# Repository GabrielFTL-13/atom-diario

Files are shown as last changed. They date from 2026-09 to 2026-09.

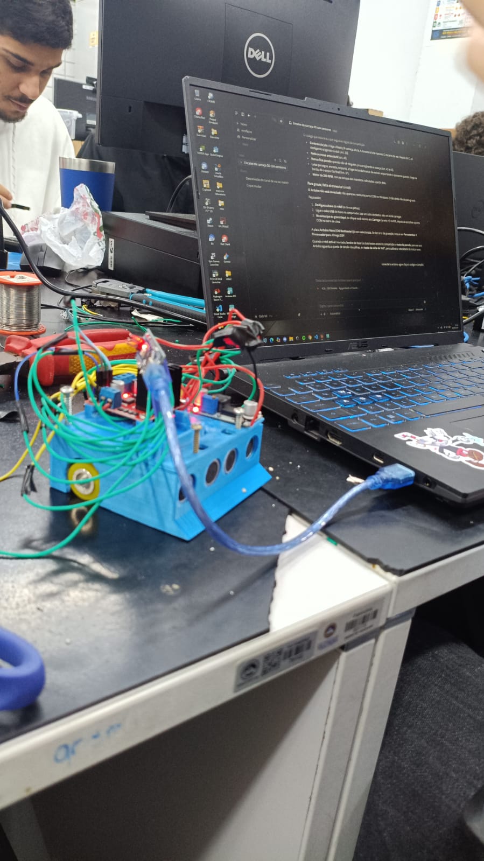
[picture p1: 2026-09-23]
img/fotos/laboratorio.jpg

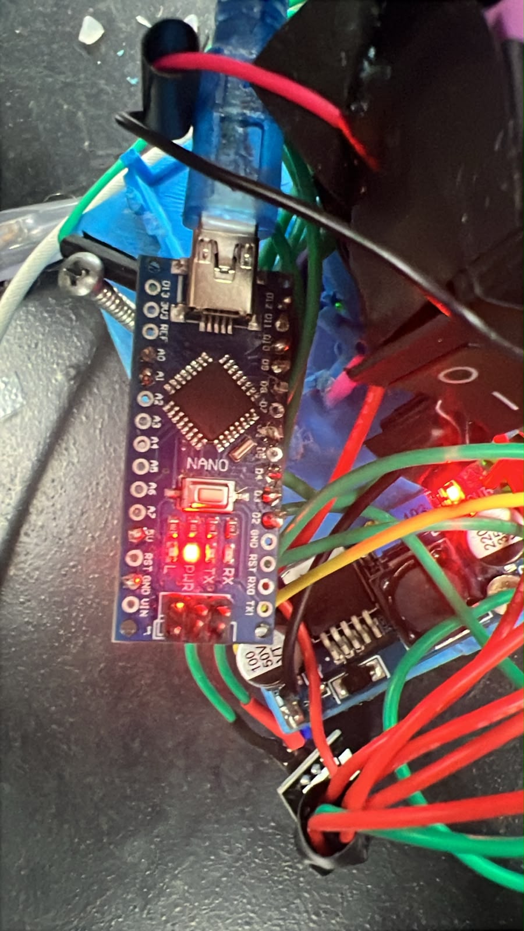
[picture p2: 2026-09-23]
img/fotos/nano_usb.jpg

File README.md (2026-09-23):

# Atom — mini sumô da UVV

Diário de bordo do **Atom**, o robô de mini sumô que a equipe levou ao **Sumô Tech Fight**
do **InovaWeek 2026** (UVV, Vila Velha, ES). O apelido dele é Frankenstein.

**Equipe:** Gabriel Fernandes, Gustavo Fernandes, Rafaela Ribeiro, Edvaldo Neto e Ana Lívia
— 2º período de Engenharia de Software, orientação do professor Abrantes.

## O site

`index.html` é o caderno completo: modelo 3D que gira, fotos, a história dos problemas e o
código gravado no robô. Abra o arquivo no navegador ou publique com o GitHub Pages
(Settings → Pages → Deploy from a branch → `main` / `root`).

## O que tem aqui

| Pasta | O que é |
| --- | --- |
| `index.html`, `modelo_r5.js`, `img/` | o site |
| `codigo/mini_sumo_uvv/` | o firmware do robô (backup 2), para Arduino Nano |
| `modelo-3d/stl/` | os STLs que foram impressos |
| `modelo-3d/openscad/` | o modelo em OpenSCAD |
| `modelo-3d/vistas/` | as vistas geradas do modelo |

## O robô

- 95 × 95 mm, 45,3 mm de altura montado
- Arduino Nano (ATmega328P), ponte H L298N
- 2× HC-SR04, 2× TCRT5000, receptor infravermelho de 38 kHz
- motores N20 de 200 RPM, rodas de 22 mm
- 2× 18650 em série com LM2596 regulando 5 V

O firmware precisa da biblioteca **IRremote 4.x** (shirriff, z3t0, ArminJo) e da placa
Arduino Nano com processador ATmega328P.

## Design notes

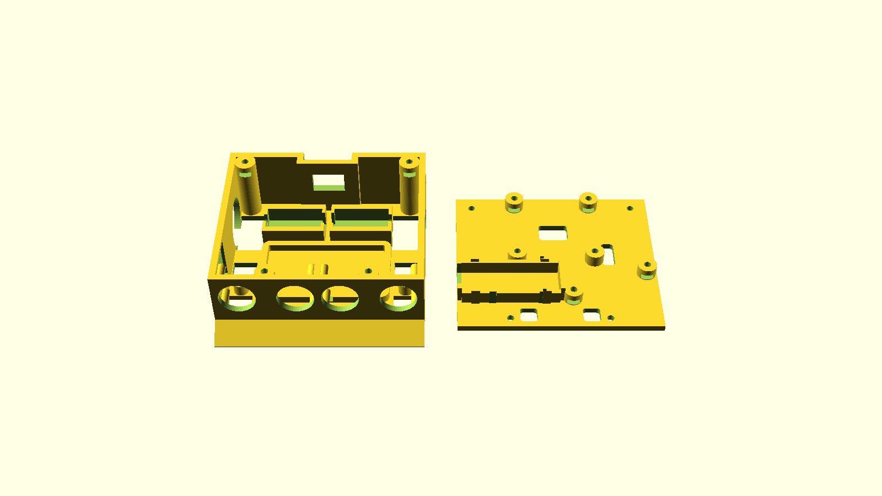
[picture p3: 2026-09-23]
img/vista_impressao_r5.png

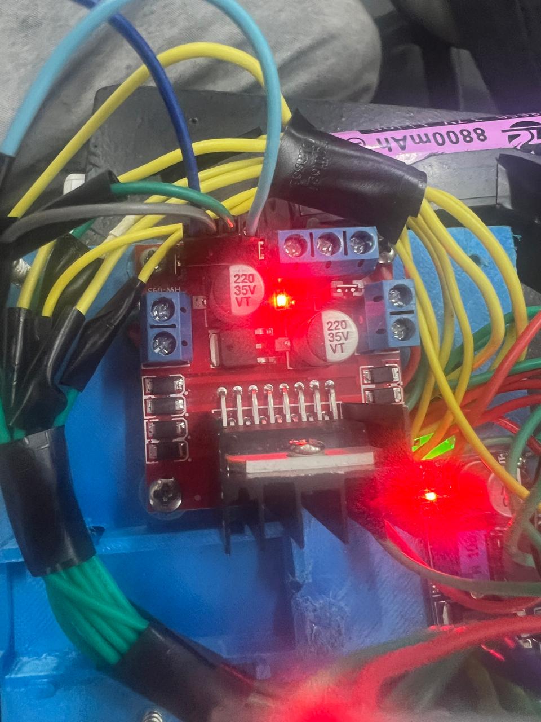
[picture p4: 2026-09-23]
img/fotos/ponte_h.jpg

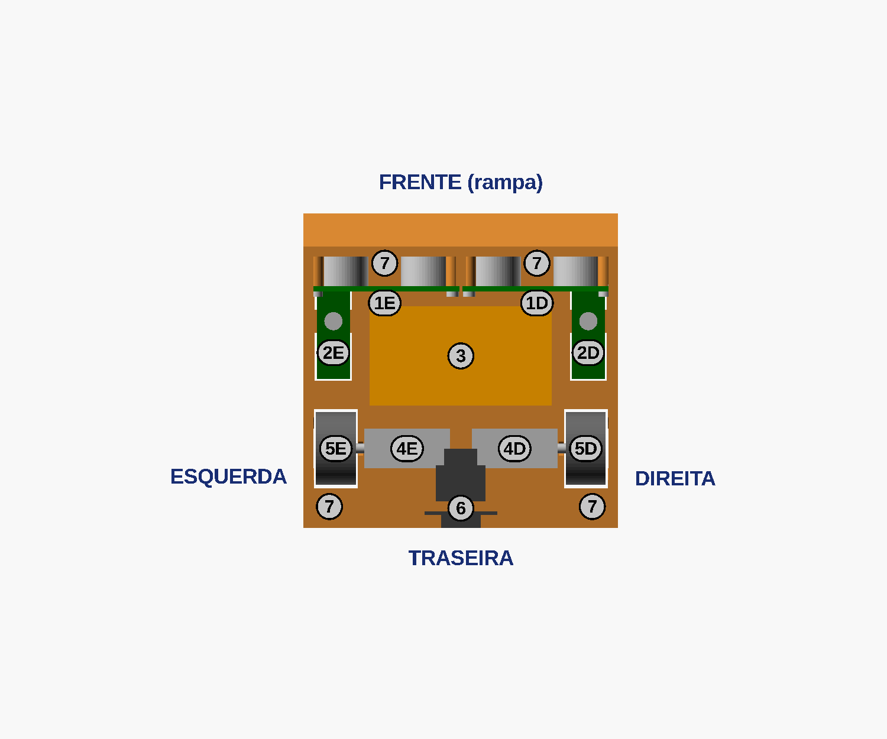
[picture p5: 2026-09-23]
img/mapa_base_r5.png

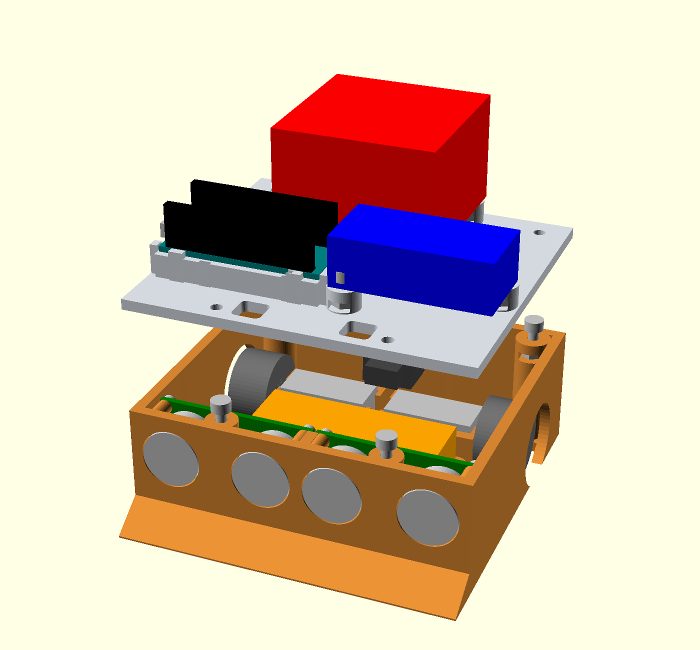
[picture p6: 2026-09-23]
img/vista_explodida_r5.png

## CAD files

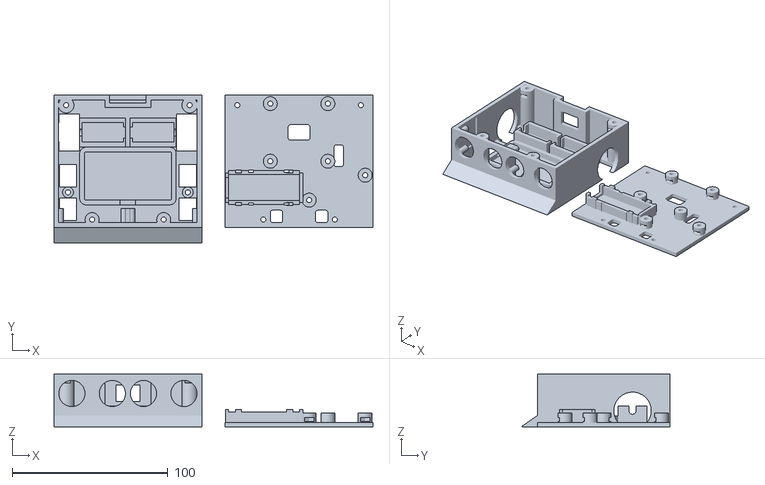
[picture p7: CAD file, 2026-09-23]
modelo-3d/stl/mini_sumo_95_r5.stl
205.0 x 95.0 x 34.0

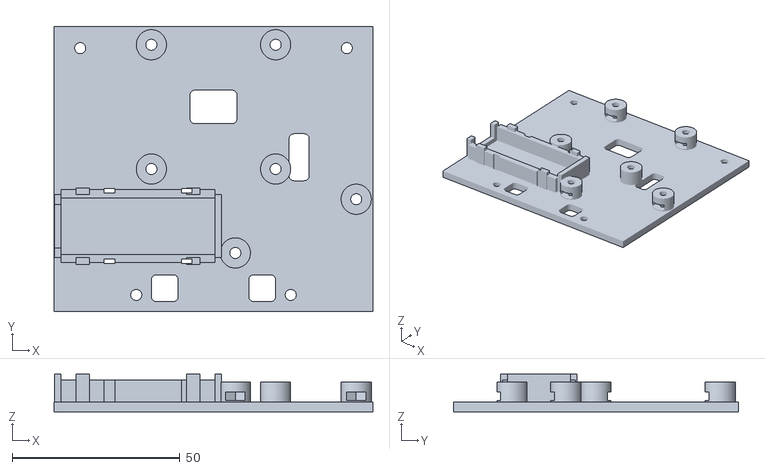
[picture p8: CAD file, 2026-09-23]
modelo-3d/stl/mini_sumo_95_r5_tampa.stl
95.0 x 85.0 x 11.3

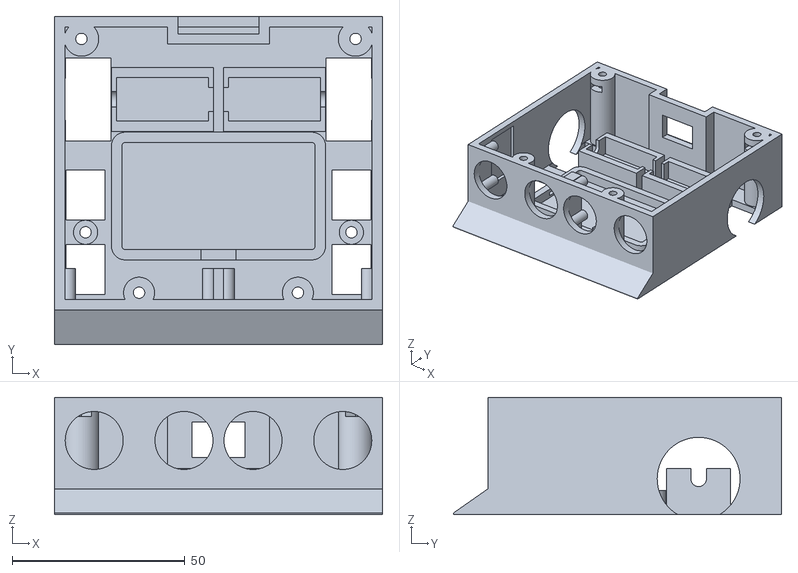
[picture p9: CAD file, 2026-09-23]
modelo-3d/stl/mini_sumo_95_r5_base.stl
95.0 x 95.0 x 34.0

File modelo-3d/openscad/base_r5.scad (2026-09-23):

$fn = 60;
// MINI SUMO 95 R5 — mm. Versao basica: 95 x 95, corpo baixo,
// ultrassom na parede frontal e eletronica sobre a tampa.
// Z da base: face inferior do piso. Z da tampa: sua face inferior.
// F6 padrao: somente duas pecas, separadas e com Z minimo = 0.

/* Dimensoes gerais, impressao e tolerancias */
chassi_largura = 95;
chassi_comprimento = 95;
piso_esp = 3;
parede_esp = 3;
altura_interna = 31;
tampa_esp = 3;
folga_geral = 0.6;             // acrescimo TOTAL em X/Y
folga_placa = 0.8;
furo_m3 = 3.3;
furo_m2 = 2.3;
separacao_pecas = 15;
mostrar_referencias = false;  // referencias % somente no F5
eps = 0.02;

/* Rampa: o trecho fino e a ponta sao excecoes ao piso de 3 mm */
rampa_c = 10;
rampa_angulo = 35;
rampa_ponta = 0.5;

/* Rodas, eixo e motores: 26 ao longo de X, 12 em Y, 10 em Z */
roda_d = 22;
roda_largura = 12;
roda_x = 9.75;
roda_y = 71;
roda_folga_radial = 1.0;
roda_folga_lateral = 0.60;
roda_janela_d = 24;
cubo_d = 8;                  // envelope assumido; MEDIR
cubo_avanco_externo = 0;     // alem da face externa do pneu; MEDIR
cubo_avanco_interno = 0;     // alem da face interna do pneu; MEDIR
altura_solo_nominal = 0.60;
motor_x = 26;
motor_y = 12;
motor_z = 10;
motor_face_x = 18.25;
motor_eixo_d = 3;            // eixo D: cilindro conservador de referencia
motor_eixo_c = 9;            // comprimento util; MEDIR
motor_rpm = 500;
motor_folga = 0.60;
motor_parede = 3;
motor_batente = 1.50;          // retencao, nao parede de impacto
motor_furo_eixo = 4.5;
motor_offset_eixo_z = 0;       // medir excentricidade do eixo real
motor_terminal_janela = 7;
abracadeira_l = 3.2;
abracadeira_h = 1.5;
motor_canal_z = 3.3;
motor_cintas_x = [5, 20];

/* Bateria: nicho 56 x 31; nao apertar o pouch */
bateria_x = 55;
bateria_y = 30;
bateria_z = 15;
bateria_pos = [47.5, 43];
bateria_folga = 1.0;          // +1 total; 0.5 por lado
bateria_apoio = 1.0;          // velcro/isolante REAL, nao impresso
bateria_borda_h = 4;
bateria_borda_esp = 3;
bateria_raio = 1;
bateria_cabo_l = 10;
bateria_fita_l = 9;
bateria_fita_h = 1.5;         // alternativa: fita fina, sem apertar

/* Pilares: porcas M3 pela LATERAL, com teto resistente a tracao */
pilar_d = 10;
pilar_frente_d = 9;          // unico vao livre entre transdutores tem 9.8 mm
pilar_afastamento = 7.8;     // sobrepoe 0.2 mm a lateral: evita tangencia
pilar_frente_x = 24.5;       // eixo do modulo HC-SR04; reforca o ligamento
pilar_frente_y = 15;
pilar_traseiro_y = 88.5;
pilar_altura = piso_esp + altura_interna;
pilar_furo = furo_m3;
porca_m3_af = 5.9;           // porca AF5.5 + 0.4 mm total de folga
porca_m3_h = 2.6;
porca_teto = 3;

/* L298N: MEDIR o padrao; 37 x 37 e apenas valor inicial */
l298n_x = chassi_largura/2;
l298n_y = roda_y;
l298n_pcb_x = 43;
l298n_pcb_y = 43;
l298n_furos_x = 37;
l298n_furos_y = 37;
l298n_furo_d = furo_m3;
l298n_altura_ref = 30;        // hipotese, inclui dissipador
l298n_excesso_rigido = 1;    // reserva alem de cada borda da PCB; MEDIR
modulo_apoio_h = 6;
modulo_apoio_d = 9;
modulo_parafuso_c = 8;       // porca lateral com teto de 3 mm
pcb_esp = 1.6;

/* LM2596: eixo comprido paralelo a X; MEDIR dois furos */
lm2596_comprimento = 43;
lm2596_largura = 21;
lm2596_x = 72;
lm2596_y = 35.5;
lm2596_furos_x = 36;
lm2596_furos_y = 16;
lm2596_furos = [[-lm2596_furos_x/2,-lm2596_furos_y/2],
                [ lm2596_furos_x/2, lm2596_furos_y/2]];
lm2596_furo_d = furo_m3;
lm2596_altura = 14;

/* Nano: USB para -X, extremidade aberta; headers para cima */
nano_x = 45;
nano_y = 18;
nano_pos = [25,35.5];
nano_apoio_h = 6.5;
nano_trilho_esp = 2.5;
nano_sobreposicao = 0.6;      // apoio somente na borda da PCB
nano_guia_h = 1.8;
nano_guia_esp = 2.0;
nano_usb_l = 13;
nano_usb_corte_z = 5;        // folga para sobremolde abaixo da PCB
nano_cintas_x = [nano_pos[0]-8.5,nano_pos[0]+14.5];
nano_cintas_y = [nano_pos[1]-nano_y/2-1.5,nano_pos[1]+nano_y/2+1.5];
nano_usb_avanco = 2;         // projecao rigida do conector alem da PCB
nano_headers_h = 12;         // envelope acima da PCB; MEDIR

/* HC-SR04 R3: sensores DENTRO da carcaca. A parede frontal da base e o
   painel optico: ela leva os quatro furos, os afastadores e o alivio
   lateral. A tampa deixou de ter torre. */
hcsr04_pcb_x = 45;
hcsr04_pcb_z = 20;
hcsr04_furo_d = 16.8;
hcsr04_transdutor_d = 16.2;
hcsr04_centros = 26;
hcsr04_modulos_dist = 46;
hcsr04_angulos = [0,0];      // painel plano frontal exige 0/0
hcsr04_transdutor_c = 12;    // MEDIR
hcsr04_centro_z = 21.5;      // eixo acustico acima da face inferior do piso
hcsr04_pcb_y = rampa_c+hcsr04_transdutor_c;  // transdutor rente ao painel
hcsr04_furos_x = 41;         // MEDIR; nao e padrao universal
hcsr04_furos_z = 16;
hcsr04_apoio_d = 4.2;        // afastador integral painel -> PCB
hcsr04_apoio_furo = 1.7;     // pre-furo para M2 autoatarraxante
hcsr04_rosca_prof = 7;       // profundidade util da rosca no afastador
hcsr04_rebaixo_prof = 1.4;   // alivio na face interna das paredes laterais
hcsr04_rebaixo_y0 = 21.4;    // alivio so na faixa da PCB: afastador fica apoiado
hcsr04_rebaixo_y = hcsr04_pcb_y+pcb_esp+hcsr04_transdutor_c+0.5;
                             // cobre o curso inteiro de insercao da PCB
hcsr04_espinha_esp = 3;      // nervura central que enraiza os afastadores internos

/* TCRT5000 DO: PCB longa em Y, optica na ponta dianteira */
tcrt_pcb_c = 35;
tcrt_pcb_l = 10;
tcrt_x = 9;
tcrt_y = 32.5;
tcrt_optica_offset_y = -14.5; // centro optico em Y=18; MEDIR
tcrt_projecao_optica = 7;     // PCB inferior -> face optica; MEDIR
tcrt_distancia_solo = 2.5;
tcrt_janela_l = 11.2;
tcrt_janela_c = 36;
tcrt_ponte_l = 7;
tcrt_boss_d = 7;
tcrt_furo = furo_m3;
tcrt_porca_af = 5.7;
tcrt_porca_h = 3.2;           // profundidade do bolso; porca real ~2.4

/* Gangorra traseira recuada: medir corpo, flange e terminais */
chave_tipo = "retangular";   // "retangular" ou "circular"
chave_x = 47.5;
chave_z = 21.7;
chave_recorte_x = 15.4;
chave_recorte_z = 10.4;
chave_recorte_d = 12.4;
chave_recuo = 5;
chave_poco_x = 23.5;
chave_poco_z0 = 13;
chave_corpo_profundidade = 14; // desde o plano externo do painel; MEDIR
chave_corpo_x = 15;
chave_corpo_z = 10;
chave_flange_x = 22;
chave_flange_z = 14;
chave_flange_esp = 1;
chave_acionador_x = 12;
chave_acionador_z = 8;
chave_projecao_total = 5;     // flange + acionador, desde o painel; MEDIR
chave_terminais_c = 5;
chave_terminais_x = 10;
chave_terminais_z = 6;

/* Ferragens reais: somente referencias; medir cabecas/porcas */
m3_d = 3;
m3_cabeca_d = 5.5;
m3_cabeca_h = 3;
m3_porca_af_real = 5.5;
m3_porca_h_real = 2.4;
tampa_parafuso_c = 10;
tcrt_parafuso_c = 10;
m2_d = 2;
m2_cabeca_d = 3.8;
m2_cabeca_h = 1.6;
m2_porca_af_real = 4;
m2_porca_h_real = 1.6;
hc_parafuso_c = 8;           // M2 autoatarraxante no afastador

/* Cabos: janelas no corredor entre modulos e na lateral */
cabos_janelas = [[47.5,71,14,10],[73,56,6,14],
                 [33,17,8,8],[62,17,8,8]];
cabos_canto_r = 1.5;

/* Derivados */
W = chassi_largura;
L = chassi_comprimento;
eixo_z = roda_d/2-altura_solo_nominal;
motor_apoio_z = eixo_z-motor_z/2-motor_offset_eixo_z;
motor_cx = motor_face_x+motor_x/2;
tcrt_apoio_z = tcrt_distancia_solo-altura_solo_nominal
              +tcrt_projecao_optica;
bat_ix = bateria_x+bateria_folga;
bat_iy = bateria_y+bateria_folga;
hc_x = [(W-hcsr04_modulos_dist)/2,(W+hcsr04_modulos_dist)/2];
pilares = [[pilar_frente_x,pilar_frente_y,pilar_frente_d],
           [W-pilar_frente_x,pilar_frente_y,pilar_frente_d],
           [pilar_afastamento,pilar_traseiro_y,pilar_d],
           [W-pilar_afastamento,pilar_traseiro_y,pilar_d]];
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

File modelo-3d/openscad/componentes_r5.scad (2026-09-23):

$fn = 60;
// MINI SUMO 95 R5 — mm. Versao basica: 95 x 95, corpo baixo,
// ultrassom na parede frontal e eletronica sobre a tampa.
// Z da base: face inferior do piso. Z da tampa: sua face inferior.
// F6 padrao: somente duas pecas, separadas e com Z minimo = 0.

/* Dimensoes gerais, impressao e tolerancias */
chassi_largura = 95;
chassi_comprimento = 95;
piso_esp = 3;
parede_esp = 3;
altura_interna = 31;
tampa_esp = 3;
folga_geral = 0.6;             // acrescimo TOTAL em X/Y
folga_placa = 0.8;
furo_m3 = 3.3;
furo_m2 = 2.3;
separacao_pecas = 15;
mostrar_referencias = false;  // referencias % somente no F5
eps = 0.02;

/* Rampa: o trecho fino e a ponta sao excecoes ao piso de 3 mm */
rampa_c = 10;
rampa_angulo = 35;
rampa_ponta = 0.5;

/* Rodas, eixo e motores: 26 ao longo de X, 12 em Y, 10 em Z */
roda_d = 22;
roda_largura = 12;
roda_x = 9.75;
roda_y = 71;
roda_folga_radial = 1.0;
roda_folga_lateral = 0.60;
roda_janela_d = 24;
cubo_d = 8;                  // envelope assumido; MEDIR
cubo_avanco_externo = 0;     // alem da face externa do pneu; MEDIR
cubo_avanco_interno = 0;     // alem da face interna do pneu; MEDIR
altura_solo_nominal = 0.60;
motor_x = 26;
motor_y = 12;
motor_z = 10;
motor_face_x = 18.25;
motor_eixo_d = 3;            // eixo D: cilindro conservador de referencia
motor_eixo_c = 9;            // comprimento util; MEDIR
motor_rpm = 500;
motor_folga = 0.60;
motor_parede = 3;
motor_batente = 1.50;          // retencao, nao parede de impacto
motor_furo_eixo = 4.5;
motor_offset_eixo_z = 0;       // medir excentricidade do eixo real
motor_terminal_janela = 7;
abracadeira_l = 3.2;
abracadeira_h = 1.5;
motor_canal_z = 3.3;
motor_cintas_x = [5, 20];

/* Bateria: nicho 56 x 31; nao apertar o pouch */
bateria_x = 55;
bateria_y = 30;
bateria_z = 15;
bateria_pos = [47.5, 43];
bateria_folga = 1.0;          // +1 total; 0.5 por lado
bateria_apoio = 1.0;          // velcro/isolante REAL, nao impresso
bateria_borda_h = 4;
bateria_borda_esp = 3;
bateria_raio = 1;
bateria_cabo_l = 10;
bateria_fita_l = 9;
bateria_fita_h = 1.5;         // alternativa: fita fina, sem apertar

/* Pilares: porcas M3 pela LATERAL, com teto resistente a tracao */
pilar_d = 10;
pilar_frente_d = 9;          // unico vao livre entre transdutores tem 9.8 mm
pilar_afastamento = 7.8;     // sobrepoe 0.2 mm a lateral: evita tangencia
pilar_frente_x = 24.5;       // eixo do modulo HC-SR04; reforca o ligamento
pilar_frente_y = 15;
pilar_traseiro_y = 88.5;
pilar_altura = piso_esp + altura_interna;
pilar_furo = furo_m3;
porca_m3_af = 5.9;           // porca AF5.5 + 0.4 mm total de folga
porca_m3_h = 2.6;
porca_teto = 3;

/* L298N: MEDIR o padrao; 37 x 37 e apenas valor inicial */
l298n_x = chassi_largura/2;
l298n_y = roda_y;
l298n_pcb_x = 43;
l298n_pcb_y = 43;
l298n_furos_x = 37;
l298n_furos_y = 37;
l298n_furo_d = furo_m3;
l298n_altura_ref = 30;        // hipotese, inclui dissipador
l298n_excesso_rigido = 1;    // reserva alem de cada borda da PCB; MEDIR
modulo_apoio_h = 6;
modulo_apoio_d = 9;
modulo_parafuso_c = 8;       // porca lateral com teto de 3 mm
pcb_esp = 1.6;

/* LM2596: eixo comprido paralelo a X; MEDIR dois furos */
lm2596_comprimento = 43;
lm2596_largura = 21;
lm2596_x = 72;
lm2596_y = 35.5;
lm2596_furos_x = 36;
lm2596_furos_y = 16;
lm2596_furos = [[-lm2596_furos_x/2,-lm2596_furos_y/2],
                [ lm2596_furos_x/2, lm2596_furos_y/2]];
lm2596_furo_d = furo_m3;
lm2596_altura = 14;

/* Nano: USB para -X, extremidade aberta; headers para cima */
nano_x = 45;
nano_y = 18;
nano_pos = [25,35.5];
nano_apoio_h = 6.5;
nano_trilho_esp = 2.5;
nano_sobreposicao = 0.6;      // apoio somente na borda da PCB
nano_guia_h = 1.8;
nano_guia_esp = 2.0;
nano_usb_l = 13;
nano_usb_corte_z = 5;        // folga para sobremolde abaixo da PCB
nano_cintas_x = [nano_pos[0]-8.5,nano_pos[0]+14.5];
nano_cintas_y = [nano_pos[1]-nano_y/2-1.5,nano_pos[1]+nano_y/2+1.5];
nano_usb_avanco = 2;         // projecao rigida do conector alem da PCB
nano_headers_h = 12;         // envelope acima da PCB; MEDIR

/* HC-SR04 R3: sensores DENTRO da carcaca. A parede frontal da base e o
   painel optico: ela leva os quatro furos, os afastadores e o alivio
   lateral. A tampa deixou de ter torre. */
hcsr04_pcb_x = 45;
hcsr04_pcb_z = 20;
hcsr04_furo_d = 16.8;
hcsr04_transdutor_d = 16.2;
hcsr04_centros = 26;
hcsr04_modulos_dist = 46;
hcsr04_angulos = [0,0];      // painel plano frontal exige 0/0
hcsr04_transdutor_c = 12;    // MEDIR
hcsr04_centro_z = 21.5;      // eixo acustico acima da face inferior do piso
hcsr04_pcb_y = rampa_c+hcsr04_transdutor_c;  // transdutor rente ao painel
hcsr04_furos_x = 41;         // MEDIR; nao e padrao universal
hcsr04_furos_z = 16;
hcsr04_apoio_d = 4.2;        // afastador integral painel -> PCB
hcsr04_apoio_furo = 1.7;     // pre-furo para M2 autoatarraxante
hcsr04_rosca_prof = 7;       // profundidade util da rosca no afastador
hcsr04_rebaixo_prof = 1.4;   // alivio na face interna das paredes laterais
hcsr04_rebaixo_y0 = 21.4;    // alivio so na faixa da PCB: afastador fica apoiado
hcsr04_rebaixo_y = hcsr04_pcb_y+pcb_esp+hcsr04_transdutor_c+0.5;
                             // cobre o curso inteiro de insercao da PCB
hcsr04_espinha_esp = 3;      // nervura central que enraiza os afastadores internos

/* TCRT5000 DO: PCB longa em Y, optica na ponta dianteira */
tcrt_pcb_c = 35;
tcrt_pcb_l = 10;
tcrt_x = 9;
tcrt_y = 32.5;
tcrt_optica_offset_y = -14.5; // centro optico em Y=18; MEDIR
tcrt_projecao_optica = 7;     // PCB inferior -> face optica; MEDIR
tcrt_distancia_solo = 2.5;
tcrt_janela_l = 11.2;
tcrt_janela_c = 36;
tcrt_ponte_l = 7;
tcrt_boss_d = 7;
tcrt_furo = furo_m3;
tcrt_porca_af = 5.7;
tcrt_porca_h = 3.2;           // profundidade do bolso; porca real ~2.4

/* Gangorra traseira recuada: medir corpo, flange e terminais */
chave_tipo = "retangular";   // "retangular" ou "circular"
chave_x = 47.5;
chave_z = 21.7;
chave_recorte_x = 15.4;
chave_recorte_z = 10.4;
chave_recorte_d = 12.4;
chave_recuo = 5;
chave_poco_x = 23.5;
chave_poco_z0 = 13;
chave_corpo_profundidade = 14; // desde o plano externo do painel; MEDIR
chave_corpo_x = 15;
chave_corpo_z = 10;
chave_flange_x = 22;
chave_flange_z = 14;
chave_flange_esp = 1;
chave_acionador_x = 12;
chave_acionador_z = 8;
chave_projecao_total = 5;     // flange + acionador, desde o painel; MEDIR
chave_terminais_c = 5;
chave_terminais_x = 10;
chave_terminais_z = 6;

/* Ferragens reais: somente referencias; medir cabecas/porcas */
m3_d = 3;
m3_cabeca_d = 5.5;
m3_cabeca_h = 3;
m3_porca_af_real = 5.5;
m3_porca_h_real = 2.4;
tampa_parafuso_c = 10;
tcrt_parafuso_c = 10;
m2_d = 2;
m2_cabeca_d = 3.8;
m2_cabeca_h = 1.6;
m2_porca_af_real = 4;
m2_porca_h_real = 1.6;
hc_parafuso_c = 8;           // M2 autoatarraxante no afastador

/* Cabos: janelas no corredor entre modulos e na lateral */
cabos_janelas = [[47.5,71,14,10],[73,56,6,14],
                 [33,17,8,8],[62,17,8,8]];
cabos_canto_r = 1.5;

/* Derivados */
W = chassi_largura;
L = chassi_comprimento;
eixo_z = roda_d/2-altura_solo_nominal;
motor_apoio_z = eixo_z-motor_z/2-motor_offset_eixo_z;
motor_cx = motor_face_x+motor_x/2;
tcrt_apoio_z = tcrt_distancia_solo-altura_solo_nominal
              +tcrt_projecao_optica;
bat_ix = bateria_x+bateria_folga;
bat_iy = bateria_y+bateria_folga;
hc_x = [(W-hcsr04_modulos_dist)/2,(W+hcsr04_modulos_dist)/2];
pilares = [[pilar_frente_x,pilar_frente_y,pilar_frente_d],
           [W-pilar_frente_x,pilar_frente_y,pilar_frente_d],
           [pilar_afastamento,pilar_traseiro_y,pilar_d],
           [W-pilar_afastamento,pilar_traseiro_y,pilar_d]];
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

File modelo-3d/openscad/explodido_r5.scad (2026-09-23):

$fn = 60;
// MINI SUMO 95 R5 — mm. Versao basica: 95 x 95, corpo baixo,
// ultrassom na parede frontal e eletronica sobre a tampa.
// Z da base: face inferior do piso. Z da tampa: sua face inferior.
// F6 padrao: somente duas pecas, separadas e com Z minimo = 0.

/* Dimensoes gerais, impressao e tolerancias */
chassi_largura = 95;
chassi_comprimento = 95;
piso_esp = 3;
parede_esp = 3;
altura_interna = 31;
tampa_esp = 3;
folga_geral = 0.6;             // acrescimo TOTAL em X/Y
folga_placa = 0.8;
furo_m3 = 3.3;
furo_m2 = 2.3;
separacao_pecas = 15;
mostrar_referencias = false;  // referencias % somente no F5
eps = 0.02;

/* Rampa: o trecho fino e a ponta sao excecoes ao piso de 3 mm */
rampa_c = 10;
rampa_angulo = 35;
rampa_ponta = 0.5;

/* Rodas, eixo e motores: 26 ao longo de X, 12 em Y, 10 em Z */
roda_d = 22;
roda_largura = 12;
roda_x = 9.75;
roda_y = 71;
roda_folga_radial = 1.0;
roda_folga_lateral = 0.60;
roda_janela_d = 24;
cubo_d = 8;                  // envelope assumido; MEDIR
cubo_avanco_externo = 0;     // alem da face externa do pneu; MEDIR
cubo_avanco_interno = 0;     // alem da face interna do pneu; MEDIR
altura_solo_nominal = 0.60;
motor_x = 26;
motor_y = 12;
motor_z = 10;
motor_face_x = 18.25;
motor_eixo_d = 3;            // eixo D: cilindro conservador de referencia
motor_eixo_c = 9;            // comprimento util; MEDIR
motor_rpm = 500;
motor_folga = 0.60;
motor_parede = 3;
motor_batente = 1.50;          // retencao, nao parede de impacto
motor_furo_eixo = 4.5;
motor_offset_eixo_z = 0;       // medir excentricidade do eixo real
motor_terminal_janela = 7;
abracadeira_l = 3.2;
abracadeira_h = 1.5;
motor_canal_z = 3.3;
motor_cintas_x = [5, 20];

/* Bateria: nicho 56 x 31; nao apertar o pouch */
bateria_x = 55;
bateria_y = 30;
bateria_z = 15;
bateria_pos = [47.5, 43];
bateria_folga = 1.0;          // +1 total; 0.5 por lado
bateria_apoio = 1.0;          // velcro/isolante REAL, nao impresso
bateria_borda_h = 4;
bateria_borda_esp = 3;
bateria_raio = 1;
bateria_cabo_l = 10;
bateria_fita_l = 9;
bateria_fita_h = 1.5;         // alternativa: fita fina, sem apertar

/* Pilares: porcas M3 pela LATERAL, com teto resistente a tracao */
pilar_d = 10;
pilar_frente_d = 9;          // unico vao livre entre transdutores tem 9.8 mm
pilar_afastamento = 7.8;     // sobrepoe 0.2 mm a lateral: evita tangencia
pilar_frente_x = 24.5;       // eixo do modulo HC-SR04; reforca o ligamento
pilar_frente_y = 15;
pilar_traseiro_y = 88.5;
pilar_altura = piso_esp + altura_interna;
pilar_furo = furo_m3;
porca_m3_af = 5.9;           // porca AF5.5 + 0.4 mm total de folga
porca_m3_h = 2.6;
porca_teto = 3;

/* L298N: MEDIR o padrao; 37 x 37 e apenas valor inicial */
l298n_x = chassi_largura/2;
l298n_y = roda_y;
l298n_pcb_x = 43;
l298n_pcb_y = 43;
l298n_furos_x = 37;
l298n_furos_y = 37;
l298n_furo_d = furo_m3;
l298n_altura_ref = 30;        // hipotese, inclui dissipador
l298n_excesso_rigido = 1;    // reserva alem de cada borda da PCB; MEDIR
modulo_apoio_h = 6;
modulo_apoio_d = 9;
modulo_parafuso_c = 8;       // porca lateral com teto de 3 mm
pcb_esp = 1.6;

/* LM2596: eixo comprido paralelo a X; MEDIR dois furos */
lm2596_comprimento = 43;
lm2596_largura = 21;
lm2596_x = 72;
lm2596_y = 35.5;
lm2596_furos_x = 36;
lm2596_furos_y = 16;
lm2596_furos = [[-lm2596_furos_x/2,-lm2596_furos_y/2],
                [ lm2596_furos_x/2, lm2596_furos_y/2]];
lm2596_furo_d = furo_m3;
lm2596_altura = 14;

/* Nano: USB para -X, extremidade aberta; headers para cima */
nano_x = 45;
nano_y = 18;
nano_pos = [25,35.5];
nano_apoio_h = 6.5;
nano_trilho_esp = 2.5;
nano_sobreposicao = 0.6;      // apoio somente na borda da PCB
nano_guia_h = 1.8;
nano_guia_esp = 2.0;
nano_usb_l = 13;
nano_usb_corte_z = 5;        // folga para sobremolde abaixo da PCB
nano_cintas_x = [nano_pos[0]-8.5,nano_pos[0]+14.5];
nano_cintas_y = [nano_pos[1]-nano_y/2-1.5,nano_pos[1]+nano_y/2+1.5];
nano_usb_avanco = 2;         // projecao rigida do conector alem da PCB
nano_headers_h = 12;         // envelope acima da PCB; MEDIR

/* HC-SR04 R3: sensores DENTRO da carcaca. A parede frontal da base e o
   painel optico: ela leva os quatro furos, os afastadores e o alivio
   lateral. A tampa deixou de ter torre. */
hcsr04_pcb_x = 45;
hcsr04_pcb_z = 20;
hcsr04_furo_d = 16.8;
hcsr04_transdutor_d = 16.2;
hcsr04_centros = 26;
hcsr04_modulos_dist = 46;
hcsr04_angulos = [0,0];      // painel plano frontal exige 0/0
hcsr04_transdutor_c = 12;    // MEDIR
hcsr04_centro_z = 21.5;      // eixo acustico acima da face inferior do piso
hcsr04_pcb_y = rampa_c+hcsr04_transdutor_c;  // transdutor rente ao painel
hcsr04_furos_x = 41;         // MEDIR; nao e padrao universal
hcsr04_furos_z = 16;
hcsr04_apoio_d = 4.2;        // afastador integral painel -> PCB
hcsr04_apoio_furo = 1.7;     // pre-furo para M2 autoatarraxante
hcsr04_rosca_prof = 7;       // profundidade util da rosca no afastador
hcsr04_rebaixo_prof = 1.4;   // alivio na face interna das paredes laterais
hcsr04_rebaixo_y0 = 21.4;    // alivio so na faixa da PCB: afastador fica apoiado
hcsr04_rebaixo_y = hcsr04_pcb_y+pcb_esp+hcsr04_transdutor_c+0.5;
                             // cobre o curso inteiro de insercao da PCB
hcsr04_espinha_esp = 3;      // nervura central que enraiza os afastadores internos

/* TCRT5000 DO: PCB longa em Y, optica na ponta dianteira */
tcrt_pcb_c = 35;
tcrt_pcb_l = 10;
tcrt_x = 9;
tcrt_y = 32.5;
tcrt_optica_offset_y = -14.5; // centro optico em Y=18; MEDIR
tcrt_projecao_optica = 7;     // PCB inferior -> face optica; MEDIR
tcrt_distancia_solo = 2.5;
tcrt_janela_l = 11.2;
tcrt_janela_c = 36;
tcrt_ponte_l = 7;
tcrt_boss_d = 7;
tcrt_furo = furo_m3;
tcrt_porca_af = 5.7;
tcrt_porca_h = 3.2;           // profundidade do bolso; porca real ~2.4

/* Gangorra traseira recuada: medir corpo, flange e terminais */
chave_tipo = "retangular";   // "retangular" ou "circular"
chave_x = 47.5;
chave_z = 21.7;
chave_recorte_x = 15.4;
chave_recorte_z = 10.4;
chave_recorte_d = 12.4;
chave_recuo = 5;
chave_poco_x = 23.5;
chave_poco_z0 = 13;
chave_corpo_profundidade = 14; // desde o plano externo do painel; MEDIR
chave_corpo_x = 15;
chave_corpo_z = 10;
chave_flange_x = 22;
chave_flange_z = 14;
chave_flange_esp = 1;
chave_acionador_x = 12;
chave_acionador_z = 8;
chave_projecao_total = 5;     // flange + acionador, desde o painel; MEDIR
chave_terminais_c = 5;
chave_terminais_x = 10;
chave_terminais_z = 6;

/* Ferragens reais: somente referencias; medir cabecas/porcas */
m3_d = 3;
m3_cabeca_d = 5.5;
m3_cabeca_h = 3;
m3_porca_af_real = 5.5;
m3_porca_h_real = 2.4;
tampa_parafuso_c = 10;
tcrt_parafuso_c = 10;
m2_d = 2;
m2_cabeca_d = 3.8;
m2_cabeca_h = 1.6;
m2_porca_af_real = 4;
m2_porca_h_real = 1.6;
hc_parafuso_c = 8;           // M2 autoatarraxante no afastador

/* Cabos: janelas no corredor entre modulos e na lateral */
cabos_janelas = [[47.5,71,14,10],[73,56,6,14],
                 [33,17,8,8],[62,17,8,8]];
cabos_canto_r = 1.5;

/* Derivados */
W = chassi_largura;
L = chassi_comprimento;
eixo_z = roda_d/2-altura_solo_nominal;
motor_apoio_z = eixo_z-motor_z/2-motor_offset_eixo_z;
motor_cx = motor_face_x+motor_x/2;
tcrt_apoio_z = tcrt_distancia_solo-altura_solo_nominal
              +tcrt_projecao_optica;
bat_ix = bateria_x+bateria_folga;
bat_iy = bateria_y+bateria_folga;
hc_x = [(W-hcsr04_modulos_dist)/2,(W+hcsr04_modulos_dist)/2];
pilares = [[pilar_frente_x,pilar_frente_y,pilar_frente_d],
           [W-pilar_frente_x,pilar_frente_y,pilar_frente_d],
           [pilar_afastamento,pilar_traseiro_y,pilar_d],
           [W-pilar_afastamento,pilar_traseiro_y,pilar_d]];
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

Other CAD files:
modelo-3d/openscad/interferencia_r5.scad
modelo-3d/openscad/mini_sumo_95_r5.scad
modelo-3d/openscad/montado_r5.scad
modelo-3d/openscad/pecas_r5.scad
modelo-3d/openscad/remocao_r5.scad
modelo-3d/openscad/tampa_r5.scad

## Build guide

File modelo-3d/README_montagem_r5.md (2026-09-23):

# Mini Sumô 95 — Revisão R5 (versão básica)

Robô de **95 × 95 mm**, abaixo do limite de 10 × 10 cm, com corpo baixo. Motores,
rodas, bateria e sensores ficam dentro da base. Nano, LM2596 e L298N ficam
parafusados em cima da tampa, que é o arranjo mais comum em mini sumô.

| Medida | Valor |
| --- | ---: |
| Largura × comprimento | **95 × 95 mm** |
| Corpo fechado (base + tampa) | **37 mm** de altura |
| Nano e LM2596 sobre a tampa | até 57 mm |
| L298N com dissipador (estimativa de 30 mm) | até 73 mm |
| Base impressa | 95 × 95 × 34 mm |
| Tampa impressa | 95 × 85 × 11,3 mm |
| Volume de plástico | 92,9 cm³ (no máximo 115 g com 100 % de PLA) |

## O que mudou em relação à R3 e à R4

- **Em relação à R3:** foi corrigido o encaixe dos HC-SR04. Na R3 o alívio lateral
  onde entram as bordas das placas era curto demais, e a placa travava antes de os
  transdutores chegarem aos furos. Agora o alívio vai de Y 21,4 a Y 36,1 e cobre os
  12 mm de curso. **Não use a base da R3.**
- **Em relação à R4:** a caixa alta com a eletrônica dentro foi descartada. O robô
  voltou a ter corpo baixo.

## Verificação

Compilação CGAL no OpenSCAD 2021.01 e leitura independente dos STLs.

- **Malha:** base e tampa com 1 corpo cada, 0 arestas não-manifold, 0 orientações
  incoerentes e 0 triângulos degenerados.
- **Base × tampa montada:** só o plano de assentamento, com volume zero.
- **Componentes da base × componentes da tampa:** interseção vazia.
- **Estrutura × componentes:** 14 contatos planos. Os 44,54 mm³ sólidos são só a
  rosca dos oito M2 autoatarraxantes, o que é intencional.
- **Retirada lateral das rodas:** interseção vazia.
- **Sondas:** o curso de 12 mm da placa dos sensores está livre nas duas paredes, e
  a parede lateral continua maciça acima dessa faixa.

## Ordem de montagem

1. **Porcas M3** nos quatro pilares da base e nos seis apoios da tampa, inseridas
   pela lateral.
2. **HC-SR04, com a base ainda vazia.** Desça a placa atrás da parede frontal, por
   volta de Y 35, com as duas bordas curtas dentro do alívio lateral. Empurre 12 mm
   para a frente até os transdutores atravessarem os furos e a placa encostar nos
   afastadores. Prenda com quatro **M2 × 8 autoatarraxantes por trás**. Os dois
   parafusos de baixo do meio têm só uns 36 mm livres atrás, então use chave curta
   ou bit solto. Repita no segundo sensor.
3. TCRT5000, com a porca pela face inferior.
4. Motores N20 nos berços, presos com abraçadeira, e rodas por fora.
5. Chave liga/desliga no recuo traseiro.
6. **Bateria por último**, porque ela fica no caminho de encaixe dos sensores.
7. Na tampa: L298N, LM2596 e Nano, este preso com abraçadeiras. Os fios passam
   pelas quatro janelas da tampa.
8. Feche com quatro **M3 × 10**.

## Impressão

- **Base:** piso na mesa, sem suporte.
- **Tampa:** parte lisa na mesa, apoios para cima, sem suporte.
- Sugestão: camada de 0,2 mm, 4 perímetros e 30 % de preenchimento.
- `stl/mini_sumo_95_r5.stl` traz as duas peças separadas, prontas para fatiar juntas.

## O que ainda precisa ser medido

- Projeção do transdutor do HC-SR04 (12 mm) e furação da placa (41 × 16 mm).
- Furação do L298N (37 × 37 mm) e do LM2596 (36 × 16 mm na diagonal).
- Altura real do L298N com dissipador.

Se alguma medida real for diferente, altere o valor no `mini_sumo_95_r5.scad`. Os
`assert` do arquivo avisam se alguma folga quebrar.

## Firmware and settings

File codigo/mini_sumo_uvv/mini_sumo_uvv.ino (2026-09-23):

/*
  Mini Sumo 95 - firmware para o Sumo Tech Fight (InovaWeek 2026, UVV)
  Versao para motores N20 de 200 RPM.

  Placa: Arduino Nano (ATmega328P, 5 V)
  Biblioteca obrigatoria: IRremote (shirriff, z3t0, ArminJo), versao 4.x

  Estrategia: procurar o inimigo e, quando achar, ir RETO para cima dele.
    1. Borda branca a vista -> foge da borda. PRIORIDADE ABSOLUTA: enquanto
       um sensor de linha ve branco, nada faz o robo andar para a frente,
       nem o inimigo. So volta a atacar depois de sair do branco e de girar
       pelo menos metade da fuga.
       Excecao: se estiver empurrando o inimigo colado, da um empurrao final
       antes de fugir (Art. 37: quem conduz o oponente para fora ganha o
       ponto, mesmo encostando fora primeiro).
    2. INIMIGO A VISTA (em qualquer um dos dois sensores) -> ATACAR: as duas
       rodas para a frente com a MESMA potencia (VEL_ATAQUE). Sem curva e sem
       mira: anda reto e empurra. ATAQUE TRAVADO: colado no inimigo o HC-SR04
       nao le, entao o robo continua empurrando reto, sem parar, por ate 3 s
       sem leitura. Se o inimigo foi visto longe, espera so meio segundo.
    3. Nada a vista -> BUSCA: gira 3/4 de volta para o lado onde viu o
       inimigo por ultimo e anda 10 cm para a frente, procurando de novo.
  Sensor de linha desregulado (travado em BRANCO ou piscando entre branco e
  preto) e ignorado ate ler preto firme, para o robo nao ficar girando para
  sempre fugindo de uma borda que nao existe.

  Com motor de 200 RPM o robo e lento, entao os tempos das manobras nao sao
  fixos: saem da velocidade do motor, do diametro da roda e da distancia entre
  as rodas. Ajuste FATOR_VELOCIDADE com o teste TESTE_GIRO_360 (ver README).

  Regras atendidas:
    Art. 18/33  Receptor IR 38 kHz e controle RoboCore ........ processarControle()
    Anexo A.2   A=0x0C (Ready), B=0x18 (Start), C=0x5E (Stop) .. TECLA_*
    Figura 6    Inicio -A-> Ready -B-> Start -A-> Ready (pausa)
                qualquer estado -C-> Stop -> fim ................ processarControle()
    Art. 33     Stop so sai desligando e ligando o robo ........ encerrar()
    Art. 41     Nada se move antes do Start .................... setup(), manterParado()
    Art. 42/43  Nunca fica parado e sempre busca o oponente .... lutar()

  Ligacoes: todas no bloco PINOS, logo abaixo. Confira com a fiacao do robo
  antes de gravar; o programa "descobrir_pinos" mostra onde esta cada sensor.
  Motor ESQUERDO no OUT1/OUT2 do L298N e DIREITO no OUT3/OUT4. Com o jumper no
  ENA e no ENB, deixe MOTOR_COM_PWM = false.

  Diagnostico: em Inicio e Ready, o Monitor Serial (115200) mostra os sensores
  e cada sinal do controle recebido, e o LED "L" pisca a cada sinal.
*/

#define DECODE_NEC               // o controle RoboCore usa protocolo NEC
#include <IRremote.hpp>

// ================================================================ PINOS
// CONFIRA COM A FIACAO DO SEU ROBO. Se nao souber em que pino esta cada fio,
// grave o programa "descobrir_pinos" (pasta codigo/descobrir_pinos), abra o
// Monitor Serial a 115200 e siga o README. Depois troque os numeros aqui.
// Esquerda e direita sao do ponto de vista do robo, olhando por tras.
// Ao ligar, o robo avisa no Monitor Serial se algum pino foi usado 2 vezes.
//
// Pinos abaixo descobertos no robo com o programa descobrir_pinos (a fiacao
// do robo e diferente da planejada no inicio).
const uint8_t SEM_PINO       = 255;  // fio nao ligado no Arduino
const uint8_t PINO_IR        = 12;   // receptor do controle: pino S (ou OUT)
const uint8_t PINO_LINHA_ESQ = A1;   // TCRT5000 esquerdo: pino DO
const uint8_t PINO_LINHA_DIR = A0;   // TCRT5000 direito: pino DO
const uint8_t PINO_TRIG_ESQ  = 10;   // HC-SR04 esquerdo
const uint8_t PINO_ECHO_ESQ  = 9;
const uint8_t PINO_TRIG_DIR  = 8;    // HC-SR04 direito
const uint8_t PINO_ECHO_DIR  = 11;
const uint8_t PINO_IN1       = 2;         // motor esquerdo, para a frente
const uint8_t PINO_IN2       = SEM_PINO;  // motor esquerdo, para tras (sem fio)
const uint8_t PINO_IN3       = 6;         // motor direito, para a frente
const uint8_t PINO_IN4       = SEM_PINO;  // motor direito, para tras (sem fio)
const uint8_t PINO_ENA       = 5;    // so usados se MOTOR_COM_PWM = true
const uint8_t PINO_ENB       = 3;
const uint8_t PINO_LED       = LED_BUILTIN;
// Pinos sem sensor: ficam em 0 V para nenhuma entrada do L298N ficar solta.
// (Os que estiverem em uso acima sao pulados automaticamente.)
const uint8_t PINOS_EM_ZERO[] = { 3, 4, 5, 7 };
// Com IN2 e IN4 sem fio o robo nao da re: foge da borda so girando.
const bool TEM_RE = PINO_IN2 != SEM_PINO && PINO_IN4 != SEM_PINO;

// ------------------------------------------- controle do juiz (Anexo A.2)
const uint16_t TECLA_READY = 0x0C;   // tecla A
const uint16_t TECLA_START = 0x18;   // tecla B
const uint16_t TECLA_STOP  = 0x5E;   // tecla C

// Controle de TREINO. O controle de 21 teclas de kit Arduino ("Car MP3") ja
// funciona sem mudar nada: as teclas 1, 2 e 3 dele mandam os mesmos codigos
// de A, B e C. O de 17 teclas (com setas) nao tem esses codigos; com true,
// as teclas 1, 2 e 3 dele passam a valer como A, B e C.
// NA COMPETICAO deixe false: so o controle do juiz deve comandar o robo.
const bool     ACEITAR_CONTROLE_KIT = false;
const uint16_t KIT_READY = 0x45;     // tecla 1 do controle de 17 teclas
const uint16_t KIT_START = 0x46;     // tecla 2
const uint16_t KIT_STOP  = 0x47;     // tecla 3

// ------------------------------------------------ motor e rodas (200 RPM)
const float RPM_MOTOR        = 200.0;  // rotacao nominal do motor
const float DIAMETRO_RODA_MM = 22.0;
const float BITOLA_MM        = 75.5;   // distancia entre o meio das duas rodas
// Velocidade real dividida pela nominal. O L298N perde uns 2 V e o robo tem
// peso e atrito. Calibre com TESTE_GIRO_360. Motor de 12 V ligado em bateria
// de 7,4 V fica perto de 0.40.
const float FATOR_VELOCIDADE = 0.80;

// Se um motor girar ao contrario, troque para true (ou inverta os fios).
const bool INVERTE_MOTOR_ESQ = false;
const bool INVERTE_MOTOR_DIR = false;

// ENA e ENB do L298N ligados no Nano (D5 e D6): true.
// Com o jumper no ENA e no ENB (motor sempre na forca maxima): false. Nesse
// caso a velocidade parcial e feita ligando e desligando os pinos IN em ciclos
// de PERIODO_PWM_SW_MS: 170 de 255, por exemplo, fica 2/3 do ciclo ligado.
const bool MOTOR_COM_PWM = false;
const unsigned long PERIODO_PWM_SW_MS = 40;

// Nivel do pino DO do TCRT5000 sobre a borda BRANCA (quase sempre LOW).
const int NIVEL_BRANCO = LOW;

// ------------------------------------------------------ sensores de alvo
const unsigned int  ALCANCE_CM        = 60;    // o dojo tem 77 cm de diametro
const unsigned int  DIST_EMPURRAR_CM  = 15;    // perto assim conta como encostado (ataque travado)
const unsigned long ESPERA_ECO_US     = 6000;  // tempo maximo ate o eco COMECAR
const unsigned long INTERVALO_PING_MS = 15;    // um sensor por vez: cada um a cada 30 ms
const unsigned long VALIDADE_MS       = 250;   // sem medida nova ha mais tempo: sem alvo
const uint8_t       CONFIRMACOES      = 2;     // leituras seguidas para aceitar alvo novo

// ---------------------------------------------------------- velocidades
// De 0 a 255. Motor de 200 RPM e lento: ataque e fuga sempre no maximo.
const int VEL_MAX            = 255;
// ATAQUE: potencia das DUAS rodas quando o inimigo aparece. E um valor so,
// usado nas duas: as rodas recebem exatamente a mesma potencia e o robo vai
// reto. 255 = maximo (roda sempre ligada, sem pulsar).
const int VEL_ATAQUE         = 255;
const int VEL_BUSCA_GIRO     = 170;   // devagar o bastante para os sensores lerem
const int VEL_BUSCA_AVANCO   = 200;

// ------------------------------------------------------------- manobras
// Em milimetros e graus; o tempo e calculado a partir da velocidade do motor.
const float RE_BORDA_MM          = 60;
const float GIRO_BORDA_GRAUS     = 135;
const float GIRO_BORDA_180_GRAUS = 180;
const float BUSCA_GIRO_GRAUS     = 270;   // gira 3/4 de volta...
const float BUSCA_AVANCO_MM      = 100;   // ...e avanca 10 cm, procurando em outro ponto
const float EMPURRAO_FINAL_MM    = 35;

// Depois de perder o inimigo de vista, continua atacando reto por mais este
// tempo (o inimigo foi visto longe por ultimo).
const unsigned long T_MEMORIA_ATAQUE_MS    = 500;
// ATAQUE TRAVADO: se o inimigo foi visto a ate DIST_EMPURRAR_CM, o robo esta
// encostado nele e o HC-SR04 nao consegue medir. Continua empurrando reto,
// sem parar, por ate este tempo sem leitura. So a borda interrompe antes.
const unsigned long T_MEMORIA_COLADO_MS    = 3000;
const unsigned long T_CONTATO_RECENTE_MS   = 150;  // para valer o empurrao final

// Empurrao final na borda. Desligue (false) se o robo estiver caindo junto.
const bool USAR_EMPURRAO_FINAL = true;

// Lado para onde comeca a procurar: +1 gira para a direita, -1 para a esquerda.
const int LADO_BUSCA_INICIAL = +1;

// Teste de calibracao: no Start o robo da uma volta de 360 graus e para.
// NUNCA deixe true na competicao: robo parado perde o ponto.
const bool TESTE_GIRO_360 = false;

// Monitor serial a 115200 para calibrar. Nunca imprime durante a luta.
const bool DEBUG_SERIAL = true;
// Mostra no Monitor Serial cada mudanca de tatica durante a luta (BUSCA,
// ATACAR, FUGA). Imprime pouco e nao atrapalha a luta.
const bool DEBUG_LUTA = true;

// Filtro dos sensores de linha. Um sensor desregulado fica travado em BRANCO
// ou piscando entre branco e preto, e o robo gira sem parar fugindo de uma
// borda que nao existe.
//   BRANCO so vale depois de T_BRANCO_FIRME_MS seguidos: tira o ruido. Nesse
//     tempo o robo anda menos de 4 mm, e a borda tem 25 mm.
//   PRETO so vale como "saiu do branco" depois de T_PRETO_FIRME_MS seguidos:
//     piscadas curtas de preto nao contam.
//   BRANCO por mais de T_LINHA_TRAVADA_MS, contando as piscadas = sensor
//     travado ou desregulado: ignorado ate ler preto firme. Fugindo da borda
//     de verdade, o sensor volta ao preto em menos de 1 s.
const unsigned long T_BRANCO_FIRME_MS  = 20;
const unsigned long T_PRETO_FIRME_MS   = 300;
const unsigned long T_LINHA_TRAVADA_MS = 3000;

// ------------------------------------------------------------- estados
enum Estado : uint8_t { INICIO, READY, START, STOP };
enum Tatica : uint8_t {
  BUSCA_GIRO, BUSCA_AVANCO, ATACAR, EMPURRAO_FINAL, FUGA_RE, FUGA_GIRO
};

const unsigned int SEM_LEITURA    = 0xFFFF;   // nada ate ALCANCE_CM
const unsigned int SENSOR_OCUPADO = 0xFFFE;   // sem medida nova (sensor ocupado)

Estado estado = INICIO;
Tatica tatica = BUSCA_GIRO;
unsigned long tTatica = 0;
unsigned long tInicioLuta = 0;
unsigned long tUltimoAlvo = 0;
unsigned long tUltimoPerto = 0;
int ultimoLado = LADO_BUSCA_INICIAL;   // -1 esquerda, +1 direita
int ladoFuga = +1;
unsigned long duracaoGiroFuga = 0;
// Estado de cada sensor de linha (ver o filtro em bordaFiltrada()).
struct Linha {
  bool ok;                      // false: sensor travado ou desregulado, ignorado
  bool branco;                  // ultima leitura
  unsigned long tMudou;         // quando a leitura mudou pela ultima vez
  bool noBranco;                // viu branco firme e ainda nao teve preto firme
  unsigned long tInicioBranco;
};
Linha linhaEsq = { true, false, 0, false, 0 };
Linha linhaDir = { true, false, 0, false, 0 };
bool bordaEsqMemo = false;
bool bordaDirMemo = false;

unsigned int distEsq = SEM_LEITURA;     // ultima distancia valida (dentro do alcance)
unsigned int distDir = SEM_LEITURA;
unsigned int leituraEsq = SEM_LEITURA;  // ultima leitura, para o Monitor Serial
unsigned int leituraDir = SEM_LEITURA;
uint8_t acertosEsq = 0;                 // 0 a 3: confianca de que ha alvo
uint8_t acertosDir = 0;
unsigned long tMedidaEsq = 0;           // hora da ultima medida de verdade
unsigned long tMedidaDir = 0;
bool pingEsquerdo = true;
unsigned long tUltimoPing = 0;
unsigned long tUltimoDebug = 0;
unsigned long tUltimoIR = 0;           // para piscar o LED a cada sinal recebido

// Velocidades estimadas e tempos das manobras, calculados no setup().
float velRetaMmS = 0;
float velGiroGrausS = 0;
unsigned long tReBorda = 0;
unsigned long tGiroBorda = 0;
unsigned long tGiroBorda180 = 0;
unsigned long tBuscaGiro = 0;
unsigned long tBuscaAvanco = 0;
unsigned long tEmpurraoFinal = 0;
unsigned long tTeste360 = 0;

// ------------------------------------------------------------ cinematica
unsigned long msReta(float mm, int pwm) {
  return (unsigned long)(1000.0 * mm / (velRetaMmS * pwm / 255.0));
}

unsigned long msGiro(float graus, int pwm) {
  return (unsigned long)(1000.0 * graus / (velGiroGrausS * pwm / 255.0));
}

void calcularManobras() {
  velRetaMmS = RPM_MOTOR * PI * DIAMETRO_RODA_MM / 60.0 * FATOR_VELOCIDADE;
  // Girando no lugar, cada roda anda em sentido oposto sobre a bitola.
  velGiroGrausS = (2.0 * velRetaMmS / BITOLA_MM) * 180.0 / PI;

  // Sem re, o giro e feito com uma roda so (a outra para): gira na metade
  // da velocidade e leva o dobro do tempo.
  unsigned long fatorGiro = TEM_RE ? 1 : 2;

  tReBorda       = msReta(RE_BORDA_MM, VEL_MAX);
  tGiroBorda     = msGiro(GIRO_BORDA_GRAUS, VEL_MAX) * fatorGiro;
  tGiroBorda180  = msGiro(GIRO_BORDA_180_GRAUS, VEL_MAX) * fatorGiro;
  tBuscaGiro     = msGiro(BUSCA_GIRO_GRAUS, VEL_BUSCA_GIRO) * fatorGiro;
  tBuscaAvanco   = msReta(BUSCA_AVANCO_MM, VEL_BUSCA_AVANCO);
  tEmpurraoFinal = msReta(EMPURRAO_FINAL_MM, VEL_MAX);
  tTeste360      = msGiro(360, VEL_MAX) * fatorGiro;
}

// ------------------------------------------------------------- motores
void escreverPino(uint8_t pino, uint8_t valor) {
  if (pino != SEM_PINO) digitalWrite(pino, valor);
}

void acionarMotor(uint8_t pinoEn, uint8_t pinoA, uint8_t pinoB, int vel, bool inverte) {
  vel = constrain(vel, -255, 255);
  if (inverte) vel = -vel;
  if (vel < 0 && pinoB == SEM_PINO) vel = 0;   // sem fio de re: so para
  if (!MOTOR_COM_PWM && vel != 0 && abs(vel) < 255) {
    bool ligado = millis() % PERIODO_PWM_SW_MS <
                  (unsigned long)abs(vel) * PERIODO_PWM_SW_MS / 255;
    vel = ligado ? (vel > 0 ? 255 : -255) : 0;
  }
  if (vel > 0) {
    escreverPino(pinoA, HIGH);
    escreverPino(pinoB, LOW);
  } else if (vel < 0) {
    escreverPino(pinoA, LOW);
    escreverPino(pinoB, HIGH);
  } else {
    escreverPino(pinoA, LOW);
    escreverPino(pinoB, LOW);
  }
  // Com jumper no ENA/ENB, D5 e D6 ficam livres e o codigo nao mexe neles.
  if (MOTOR_COM_PWM) analogWrite(pinoEn, abs(vel));
}

// Velocidades de -255 (re) a 255 (frente).
void motores(int esquerdo, int direito) {
  acionarMotor(PINO_ENA, PINO_IN1, PINO_IN2, esquerdo, INVERTE_MOTOR_ESQ);
  acionarMotor(PINO_ENB, PINO_IN3, PINO_IN4, direito, INVERTE_MOTOR_DIR);
}

void manterParado() {
  motores(0, 0);
}

// ------------------------------------------------------------- sensores
bool bordaEsquerda() { return digitalRead(PINO_LINHA_ESQ) == NIVEL_BRANCO; }
bool bordaDireita()  { return digitalRead(PINO_LINHA_DIR) == NIVEL_BRANCO; }

// Diz se o sensor ve a borda, com o filtro contra sensor desregulado (ver
// T_BRANCO_FIRME_MS, T_PRETO_FIRME_MS e T_LINHA_TRAVADA_MS).
bool bordaFiltrada(Linha &s, bool branco, unsigned long agora,
                   const __FlashStringHelper* nome) {
  if (branco != s.branco) {
    s.branco = branco;
    s.tMudou = agora;
  }
  unsigned long firme = agora - s.tMudou;      // ha quanto tempo a leitura nao muda

  if (!branco) {
    if (firme >= T_PRETO_FIRME_MS) {           // preto firme: saiu do branco
      if (!s.ok && DEBUG_SERIAL && DEBUG_LUTA) {
        Serial.print(F("luta: sensor de linha "));
        Serial.print(nome);
        Serial.println(F(" voltou a funcionar"));
      }
      s.ok = true;
      s.noBranco = false;
    }
    return false;
  }

  if (firme < T_BRANCO_FIRME_MS) return false; // branco rapido demais: ruido
  if (!s.noBranco) {
    s.noBranco = true;
    s.tInicioBranco = agora;
  }
  if (s.ok && agora - s.tInicioBranco > T_LINHA_TRAVADA_MS) {
    s.ok = false;
    if (DEBUG_SERIAL && DEBUG_LUTA) {
      Serial.print(F("luta: sensor de linha "));
      Serial.print(nome);
      Serial.println(F(" travado em BRANCO ou piscando: ignorado ate ler preto firme"));
    }
  }
  return s.ok;
}

// No Start: sensor que ja comeca BRANCO esta desregulado (o robo comeca sobre
// o preto) e fica ignorado ate ler preto firme.
void iniciarLinha(Linha &s, bool branco, unsigned long agora) {
  s.ok = !branco;
  s.branco = branco;
  s.tMudou = agora;
  s.noBranco = false;
}

// Mede a distancia em cm. O tempo do eco so comeca a contar quando o ECHO sobe:
// o HC-SR04 leva de 0,5 a 2 ms para comecar a responder, e isso nao pode
// entrar no alcance. Devolve:
//   SEM_LEITURA     nada ate ALCANCE_CM
//   SENSOR_OCUPADO  o sensor ainda esta na medida anterior (sem eco, alguns
//                   HC-SR04 seguram o ECHO alto por ate 200 ms) ou nao disparou.
//                   Nao e "sem alvo": so nao ha medida nova.
unsigned int medirCm(uint8_t pinoTrig, uint8_t pinoEcho) {
  if (digitalRead(pinoEcho) == HIGH) return SENSOR_OCUPADO;
  digitalWrite(pinoTrig, LOW);
  delayMicroseconds(2);
  digitalWrite(pinoTrig, HIGH);
  delayMicroseconds(10);
  digitalWrite(pinoTrig, LOW);

  unsigned long t0 = micros();
  while (digitalRead(pinoEcho) == LOW)
    if (micros() - t0 > ESPERA_ECO_US) return SENSOR_OCUPADO;

  unsigned long inicio = micros();
  const unsigned long limite = (unsigned long)ALCANCE_CM * 58UL;
  while (digitalRead(pinoEcho) == HIGH)
    if (micros() - inicio > limite) return SEM_LEITURA;
  return (unsigned int)((micros() - inicio) / 58UL);
}

// Confianca de 0 a 3. Alvo no alcance soma 1; leitura sem alvo tira 1, em vez
// de zerar: uma falha isolada nao faz o robo perder o oponente de vista.
void registrarLeitura(unsigned int d, unsigned int &leitura, unsigned int &dist,
                      uint8_t &acertos, unsigned long &tMedida) {
  if (d == SENSOR_OCUPADO) return;       // sem medida nova: nada muda
  leitura = d;
  tMedida = millis();
  if (d <= ALCANCE_CM) {
    dist = d;
    if (acertos < 3) acertos++;
  } else if (acertos > 0) {
    acertos--;
  }
}

// Um sensor por vez, alternando, para um nao captar o eco do outro.
void atualizarUltrassom() {
  if (millis() - tUltimoPing < INTERVALO_PING_MS) return;
  if (pingEsquerdo)
    registrarLeitura(medirCm(PINO_TRIG_ESQ, PINO_ECHO_ESQ), leituraEsq, distEsq,
                     acertosEsq, tMedidaEsq);
  else
    registrarLeitura(medirCm(PINO_TRIG_DIR, PINO_ECHO_DIR), leituraDir, distDir,
                     acertosDir, tMedidaDir);
  pingEsquerdo = !pingEsquerdo;
  tUltimoPing = millis();
}

bool engajado() {
  return tatica == ATACAR || tatica == EMPURRAO_FINAL;
}

// Alvo novo precisa de confianca CONFIRMACOES (filtra leitura falsa); com o
// alvo ja travado, 1 basta. Sensor sem medida recente nao conta.
bool vendo(uint8_t acertos, unsigned long tMedida) {
  return acertos >= (engajado() ? 1 : CONFIRMACOES) &&
         millis() - tMedida < VALIDADE_MS;
}

// --------------------------------------------------------------- estados
void imprimirTatica(Tatica t) {
  switch (t) {
    case BUSCA_GIRO:     Serial.println(F("luta: BUSCA (girando)")); break;
    case BUSCA_AVANCO:   Serial.println(F("luta: BUSCA (avancando)")); break;
    case ATACAR:         Serial.println(F("luta: INIMIGO A VISTA -> ATACAR reto, rodas iguais")); break;
    case EMPURRAO_FINAL: Serial.println(F("luta: EMPURRAO FINAL na borda")); break;
    case FUGA_RE:        Serial.println(F("luta: FUGA da borda (re)")); break;
    case FUGA_GIRO:
      Serial.print(F("luta: FUGA da borda (girando) - branco no sensor "));
      Serial.println(bordaEsqMemo && bordaDirMemo ? F("dos dois lados")
                     : bordaEsqMemo ? F("esquerdo") : F("direito"));
      break;
  }
}

void iniciarTatica(Tatica t) {
  if (t != tatica && estado == START && DEBUG_SERIAL && DEBUG_LUTA) imprimirTatica(t);
  tatica = t;
  tTatica = millis();
}

void entrarReady() {
  manterParado();
  estado = READY;
  iniciarTatica(BUSCA_GIRO);
  if (DEBUG_SERIAL) Serial.println(F(">> READY: parado, aguardando Start"));
}

void entrarStart() {
  unsigned long agora = millis();
  estado = START;
  tInicioLuta = agora;
  tUltimoAlvo = agora - 60000UL;
  tUltimoPerto = agora - 60000UL;
  ultimoLado = LADO_BUSCA_INICIAL;
  iniciarTatica(BUSCA_GIRO);
  // No Start o robo esta no centro do dojo, sobre o preto. Sensor de linha que
  // ja comeca BRANCO esta desregulado: fica ignorado ate ler preto firme.
  iniciarLinha(linhaEsq, bordaEsquerda(), agora);
  iniciarLinha(linhaDir, bordaDireita(), agora);
  if (DEBUG_SERIAL) {
    Serial.println(F(">> START: luta"));
    if (!linhaEsq.ok) Serial.println(F("luta: sensor de linha esquerdo BRANCO no Start: ignorado ate ler preto firme"));
    if (!linhaDir.ok) Serial.println(F("luta: sensor de linha direito BRANCO no Start: ignorado ate ler preto firme"));
  }
}
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
void loop() {
  processarControle();

  // Ao receber qualquer sinal infravermelho, o LED "L" inverte por 150 ms.
  // Serve para ver, sem computador, se o receptor esta funcionando.
  bool piscadaIR = millis() - tUltimoIR < 150;

  switch (estado) {
    case INICIO:                  // LED apagado
      manterParado();
      digitalWrite(PINO_LED, piscadaIR ? HIGH : LOW);
      atualizarUltrassom();       // sensores ja lendo: no Start o alvo esta travado
      if (DEBUG_SERIAL) imprimirSensores();
      break;
    case READY:                   // LED pisca devagar
      manterParado();
      piscarLed(500);
      if (piscadaIR) digitalWrite(PINO_LED, !digitalRead(PINO_LED));
      atualizarUltrassom();
      if (DEBUG_SERIAL) imprimirSensores();
      break;
    case START:                   // LED pisca rapido
      piscarLed(100);
      lutar();
      break;
    case STOP:                    // nunca chega aqui: encerrar() nao retorna
      manterParado();
      break;
  }
}

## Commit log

2026-09-23 Diario de bordo do Atom: site, codigo e modelo 3D
    [base_r5.scad, componentes_r5.scad, explodido_r5.scad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]
2026-09-23 Rodape: o caderno nasceu no dia em que decidiamos o molde
2026-09-23 Rodape: o caderno comecou em 11 e 12 de setembro, na escolha do molde
